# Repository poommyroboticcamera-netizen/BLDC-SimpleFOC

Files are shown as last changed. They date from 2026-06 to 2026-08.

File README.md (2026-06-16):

<div align="center">

# BLDC SimpleFOC

Custom STM32F405RG firmware and hardware reference files for a 3-phase BLDC inverter.







</div>

---

## Overview

`BLDC-SimpleFOC` is a hardware bring-up project for a custom 3-phase BLDC motor driver based on an STM32F405RG. The current firmware drives TIM1 complementary PWM outputs directly, adds dead-time at the timer level, reads phase voltage feedback with ADC pins, and exposes simple serial commands for early bench testing.

This repository is intended for controlled inverter testing, not finished production motor control. Start with a current-limited bench supply, low duty cycle, and oscilloscope verification before connecting a real motor load.

## What Is Included

| Area | Details |
| --- | --- |
| Firmware target | STM32F405RG using PlatformIO and Arduino |
| Runtime model | STM32duino FreeRTOS tasks |
| PWM output | TIM1 center-aligned 6-PWM complementary outputs |
| Switching frequency | `20 kHz` |
<<<<<<< HEAD
| Dead-time | `1.5us` configured in TIM1 BDTR |
=======
| Dead-time | `1.5 us` configured in TIM1 BDTR |
>>>>>>> 4c121442047dd9c6b4e7016d9e61324d03763788
| Control mode | Open-loop sinusoidal V/f style test waveform |
| Monitoring | Serial output plus phase voltage ADC reads |
| Hardware files | Schematic PDF, 3D STEP model, and firmware flow diagram |

## Repository Layout

```text
BLDC-SimpleFOC/
|-- firmware/
|   |-- include/        Project headers, when shared declarations are added
|   |-- lib/            Private PlatformIO libraries, when the firmware grows
|   |-- src/
|   |   `-- main.cpp    Main STM32 PWM, FreeRTOS, ADC, and serial logic
|   |-- test/           PlatformIO unit/integration test area
|   `-- platformio.ini  Board, framework, upload, monitor, and library config
|-- hardware/
|   |-- 3D_PCB_2026-06-15.step
|   |-- SCH_BLDC Drive_2026-06-15.pdf
|   |-- Custom FOC Firmware.drawio
|   |-- Custom FOC Firmware.drawio.png
|   |-- Custom FOC Firmware.drawio.svg
|   `-- README.md
|-- .gitattributes
|-- .gitignore
`-- README.md
```

## Hardware Pin Map

### PWM Outputs

TIM1 is configured for complementary high-side and low-side PWM outputs.

| Motor phase | High-side PWM | Low-side PWM | Timer channel |
| --- | --- | --- | --- |
| U | `PA8` | `PB13` | `TIM1_CH1 / TIM1_CH1N` |
| V | `PA9` | `PB14` | `TIM1_CH2 / TIM1_CH2N` |
| W | `PA10` | `PB15` | `TIM1_CH3 / TIM1_CH3N` |

### Phase Voltage Feedback

| Signal | MCU pin | Notes |
| --- | --- | --- |
| Phase A voltage | `PA0` | 12-bit ADC read |
| Phase B voltage | `PA1` | 12-bit ADC read |
| Phase C voltage | `PA2` | 12-bit ADC read |

The firmware currently assumes a phase voltage divider of:

```cpp
R1_PHASE = 56000.0f
R2_PHASE = 2200.0f
```

Adjust these constants in `firmware/src/main.cpp` if the resistor values on the board change.

## Firmware Behavior

The firmware creates two FreeRTOS tasks:

| Task | Period | Purpose |
| --- | ---: | --- |
| `TaskMotorControl` | `1 ms` | Updates the sinusoidal 3-phase PWM duty registers |
| `TaskMonitor` | `200 ms` | Reads serial commands, samples phase voltage ADCs, and prints telemetry |

Default runtime values:

| Setting | Default |
| --- | ---: |
| PWM frequency | `20 kHz` |
| Dead-time | `1.5us` |
| Initial duty | `5%` |
| Initial rotation speed | `1.0 deg/loop` |
| Serial baud | `115200` |

## Quick Start

Install VS Code with the PlatformIO extension, then clone and open the firmware project.

```bash
git clone https://github.com/poommyroboticcamera-netizen/BLDC-SimpleFOC.git
cd BLDC-SimpleFOC/firmware
```

Build the firmware:

```bash
pio run
```

Upload with ST-Link:

```bash
pio run --target upload
```

Open the serial monitor:

```bash
pio device monitor -b 115200
```

## Serial Commands

Commands are read from the serial monitor as one letter plus a numeric value.

| Command | Range | Example | Meaning |
| --- | --- | --- | --- |
| `D<value>` | `0` to `100` | `D5` | Set PWM duty percentage |
| `S<value>` | `0` to `20` | `S2.5` | Set electrical rotation speed in degrees per loop |

Recommended first commands:

```text
D0
S1
D2
D5
```

Increase duty slowly while watching the bench supply current and oscilloscope waveforms.

## Bring-Up Checklist

1. Confirm the schematic matches the PWM and ADC pin map above.
2. Power only the logic side and verify the serial boot message.
3. Scope `PA8`, `PA9`, `PA10`, `PB13`, `PB14`, and `PB15` before enabling motor power.
4. Confirm complementary PWM timing and dead-time.
5. Enable the gate driver with a current-limited supply.
6. Start with `D0`, then raise duty in small steps.
7. Verify phase order before connecting a mechanical load.
8. Add current sensing, fault handling, and closed-loop feedback before high-power testing.

## Hardware Documents

The hardware folder contains the current reference files:

| File | Purpose |
| --- | --- |
| [`SCH_BLDC Drive_2026-06-15.pdf`](hardware/SCH_BLDC%20Drive_2026-06-15.pdf) | Schematic export |
| [`3D_PCB_2026-06-15.step`](hardware/3D_PCB_2026-06-15.step) | 3D PCB model for mechanical review |
| [`Custom FOC Firmware.drawio.png`](hardware/Custom%20FOC%20Firmware.drawio.png) | Firmware flow diagram preview |
| [`Custom FOC Firmware.drawio`](hardware/Custom%20FOC%20Firmware.drawio) | Editable draw.io diagram |

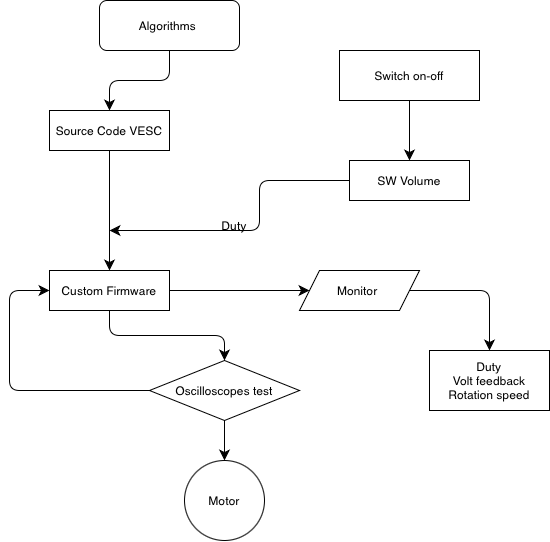
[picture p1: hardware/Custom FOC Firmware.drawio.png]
Firmware flow diagram


## Roadmap

- [ ] Clean up firmware comments and source encoding
- [ ] Add gate-driver enable and fault input handling
- [ ] Add current sensing and over-current protection
- [ ] Add magnetic encoder or Hall sensor feedback
- [ ] Add closed-loop FOC control after hardware validation
- [ ] Add known-good motor settings and oscilloscope captures
- [ ] Add PlatformIO CI build check

## Safety Notes

- Treat the inverter as high-energy hardware even at low voltage.
- Use a current-limited bench supply during first tests.
- Keep duty cycle low until all six PWM channels are verified.
- Do not run high power without fault handling and current protection.
- Disconnect motor power before changing wiring or probing low-side gate signals.

## Links

- Repository: [poommyroboticcamera-netizen/BLDC-SimpleFOC](https://github.com/poommyroboticcamera-netizen/BLDC-SimpleFOC)
- PlatformIO documentation: [docs.platformio.org](https://docs.platformio.org/)
- STM32duino documentation: [github.com/stm32duino](https://github.com/stm32duino)

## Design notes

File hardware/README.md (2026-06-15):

# Hardware

Hardware reference files for the custom STM32F405RG 3-phase BLDC driver.

## Files

| File | Description |
| --- | --- |
| [`SCH_BLDC Drive_2026-06-15.pdf`](SCH_BLDC%20Drive_2026-06-15.pdf) | Schematic export for electrical review |
| [`3D_PCB_2026-06-15.step`](3D_PCB_2026-06-15.step) | STEP model for mechanical fit checks and enclosure planning |
| [`Custom FOC Firmware.drawio`](Custom%20FOC%20Firmware.drawio) | Editable draw.io firmware/control-flow diagram |
| [`Custom FOC Firmware.drawio.png`](Custom%20FOC%20Firmware.drawio.png) | PNG preview of the firmware/control-flow diagram |
| [`Custom FOC Firmware.drawio.svg`](Custom%20FOC%20Firmware.drawio.svg) | SVG version of the diagram for scalable viewing |

## Firmware Flow Preview

Firmware flow diagram

## Board Interface Summary

| Function | Pins |
| --- | --- |
| High-side PWM | `PA8`, `PA9`, `PA10` |
| Low-side PWM | `PB13`, `PB14`, `PB15` |
| Phase voltage ADC | `PA0`, `PA1`, `PA2` |

## Review Checklist

- Confirm PWM pins match the gate-driver inputs in the schematic.
- Confirm the ADC phase-voltage divider values match the firmware constants.
- Verify gate-driver enable, fault, and protection pins before high-power tests.
- Check copper clearance, creepage, and thermal paths for the target bus voltage.
- Use the STEP file to check connector access, heatsink clearance, and mounting holes.

## Suggested Future Structure

As the hardware package grows, split files into focused folders:

```text
hardware/
|-- schematics/
|-- pcb/
|-- mechanical/
|-- simulation/
|-- bom/
`-- datasheets/
```

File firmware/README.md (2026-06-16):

# Firmware

PlatformIO firmware for the custom STM32F405RG 3-phase BLDC inverter.

## Stack

| Item | Value |
| --- | --- |
| Board | `genericSTM32F405RG` |
| Platform | `ststm32` |
| Framework | Arduino |
| RTOS | STM32duino FreeRTOS |
| Upload protocol | ST-Link |
| Serial monitor | `115200` baud |

## Source Layout

```text
firmware/
|-- include/        Shared headers, when needed
|-- lib/            Private PlatformIO libraries, when needed
|-- src/
|   `-- main.cpp    Main PWM, ADC, serial, and FreeRTOS logic
|-- test/           PlatformIO tests
|-- platformio.ini
`-- README.md
```

## Current Control Logic

The current firmware is an open-loop hardware bring-up program:

- Configures TIM1 for center-aligned complementary 6-PWM output.
- Applies `1.5us` dead-time in the advanced timer.
- Generates a 3-phase sinusoidal duty pattern.
- Reads phase voltage feedback on `PA0`, `PA1`, and `PA2`.
- Uses FreeRTOS to separate motor PWM updates from serial monitoring.

## Build

```bash
pio run
```

## Upload

```bash
pio run --target upload
```

## Monitor

```bash
pio device monitor -b 115200
```

## Serial Commands

| Command | Example | Description |
| --- | --- | --- |
| `D<value>` | `D5` | Set duty cycle in percent, from `0` to `100` |
| `S<value>` | `S2.5` | Set electrical speed in degrees per control loop, from `0` to `20` |

For first power-up, begin with:

```text
D0
S1
D2
```

## Hardware Pins

| Function | Pins |
| --- | --- |
| High-side PWM | `PA8`, `PA9`, `PA10` |
| Low-side PWM | `PB13`, `PB14`, `PB15` |
| Phase voltage ADC | `PA0`, `PA1`, `PA2` |

## Bring-Up Notes

- Verify all six PWM outputs with an oscilloscope before enabling motor power.
- Keep the duty cycle low during first tests.
- Use a current-limited bench supply.
- Add current sensing and fault handling before high-power operation.

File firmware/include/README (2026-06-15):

# Firmware Include Directory

Place shared project header files here when the firmware is split into multiple modules.

## When To Use This Folder

Use `include/` for declarations that need to be shared across files in `src/` or private libraries in `lib/`.

Good candidates:

- Pin maps
- Hardware configuration constants
- Shared structs and enums
- Public function declarations for firmware modules

## Example

```cpp
// include/board_config.h
#pragma once

#define PWM_U_HIGH PA8
#define PWM_V_HIGH PA9
#define PWM_W_HIGH PA10
```

Then include it from source files:

```cpp
#include "board_config.h"
```

## Current Status

The current firmware is still compact enough to keep the main hardware configuration in `src/main.cpp`. Move constants here when the code is refactored into dedicated PWM, ADC, serial, and protection modules.

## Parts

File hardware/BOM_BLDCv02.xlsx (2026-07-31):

No. | Quantity | Comment | Designator | Footprint | Value | Manufacturer Part
1 | 3 | 2.2uF | C18,C19,C20 | C0805 | 2.2uF | CL21A225KBQNNNE
2 | 6 | 22nF | C25,C26,C27,C28,C29,C30 | C1206 | 22nF | HHV1206R7223K631NSPJ
3 | 6 | 10uF | C31,C32,C33,C34,C35,C36 | C0805 | 10uF | GRM21BR61H106KE43L
4 | 12 | 100nF | C37,C38,C39,C40,C41,C42,C43,C44,C45,C58,C82,C83 | C0805 | 100nF | C0805X104K5RAC3123
5 | 4 | 1uF | C46,C47,C48,C50 | C0805 | 1uF | FS21X105K160ECG
6 | 1 | 2.2uF | C49 | C0805 | 2.2uF | FS21X105K160ECG
7 | 2 | 100nF | C59,C61 | C1206 | 100nF | CL31B104KBCNNNC
8 | 3 | 2.2uF | C60,C62,C76 | C1206 | 2.2uF | CL31B225KBHNNNE
9 | 2 | 4.7uF | C64,C66 | C0805 | 4.7uF | CL21A475KAQNNNE
10 | 2 | 22nF | C65,C68 | C0805 | 22nF | CL21B223KBANNNC
11 | 1 | 1uF | C72 | C0805 | 1uF | CL21B105KBFNNNE
12 | 3 | 22uF | C73,C74,C75 | C0805 | 22uF | CL21A226MAQNNNE
13 | 2 | 18pF | C77,C78 | C0603 | 18pF | C1608NP0180JGTS
14 | 2 | 2.2uF | C79,C80 | C0805 | 2.2uF | CL21B225KOFNNNE
15 | 1 | 10nF | C81 | C0805 | 10nF | C2012X7R2E103K125AA
16 | 3 | FR107 | D4,D5,D6 | SMA_L4.2-W2.7-LS5.3-FD |  | FR107
17 | 1 | SS510B | D7 | SMB_L4.3-W3.6-LS5.3-RD |  | SS510B
18 | 1 | SMF12A | D8 | SOD-123_L2.8-W1.8-LS3.7-RD |  | SMF12A
19 | 1 | SMF5.0A | D10 | SOD-123_L2.8-W1.8-LS3.7-RD |  | SMF5.0A
20 | 1 | SMF3.3A | D11 | SOD-123_L2.8-W1.8-LS3.7-RD |  | SMF3.3A
21 | 1 | XY-PZ2.54V-01-10P | H2 | HDR-TH_10P-P2.54-V-M_4 |  | XY-PZ2.54V-01-10P
22 | 2 | 2.54-1*3P | H3,H4 | HDR-TH_3P-P2.54-V-M-1 |  | 2.54-1*3P
23 | 1 | 68uH | L2 | IND-SMD_L7.8-W7.0_SCD0705N | 68uH | SM7850-680M(f)
24 | 1 | KT-0805Y | LED1 | LED0805-R-RD |  | KT-0805Y
25 | 6 | IRFS7530TRL7PP | Q1,Q2,Q3,Q4,Q5,Q6 | D2PAK-7_L10.6-W9.6-P1.27-LS15.9-BR |  | IRFS7530TRL7PP
26 | 3 | EG3112D | R20,R39,R40 | SOP-8_L5.0-W3.9-P1.27-LS6.0-BL-1 |  | EG3112D
27 | 3 | 56K | R32,R59,R60 | R0805_NEW | 56K | RK73H1JTTD10R0F
28 | 6 | 10Ω | R41,R42,R43,R44,R45,R46 | R0603 | 10Ω | WF06P10R0FTL
29 | 3 | 1mΩ | R47,R50,R53 | R2512 | 1mΩ | HIXD25LR001F
30 | 6 | 1kΩ | R48,R49,R51,R52,R54,R55 | R0805 | 1kΩ | AS05W3J0102T5E
31 | 3 | 2.2kΩ | R56,R57,R58 | R0805 | 2.2kΩ | RK73B2ATTD222J
32 | 5 | 10kΩ | R61,R85,R86,R88,R89 | R0805 | 10kΩ | AS05W3J0102T5E
33 | 1 | 30kΩ | R63 | R0603 | 30kΩ | RMC060330K5%N
34 | 1 | 274kΩ | R64 | R0805 | 274kΩ | WR08X2743FTL
35 | 4 | 10kΩ | R65,R66,R69,R70 | R0603 | 10kΩ | KTR03EZPJ103
36 | 1 | 45.3kΩ | R71 | R0603 | 45.3kΩ | WR06X4532FTL
37 | 1 | 5.1kΩ | R72 | R1206 | 5.1kΩ | RK73B2BTTD512J
38 | 9 | 0Ω | R73,R74,R75,R76,R77,R78,R79,R80,R81 | R1206 | 0Ω | 1206W4F0000T5E
39 | 1 | 4.3kΩ | R82 | R0603 | 4.3kΩ | RTT034301FTP
40 | 1 | 73.2kΩ | R83 | R0603 | 73.2kΩ | TD03G7322BT
41 | 1 | 120Ω | R84 | R0805 | 120Ω | CRGCQ0805F120R
42 | 2 | 1kΩ | R87,R90 | R0805 | 1kΩ | TP0805B1K00P0510Z
43 | 4 | TS-1088-AR02016 | SW1,SW2,SW3,SW4 | SW-SMD_L3.9-W3.0-P4.45 |  | TS-1088-AR02016
44 | 2 | 1935174 | U12,U20 | CONN-TH_3P-P5.00_1935174 |  | 1935174
45 | 3 | INA181A1IDBVR | U13,U14,U15 | SOT-23-6_L2.9-W1.6-P0.95-LS2.8-TL |  | INA181A1IDBVR
46 | 1 | STM32F405RGT6 | U18 | LQFP-64_L10.0-W10.0-P0.50-LS12.0-BL |  | STM32F405RGT6
47 | 3 | xh2.54-4p | U19,U27,U28 | CONN-TH_4P-P2.50-XH2.54-4P |  | xh2.54-4p
48 | 1 | SCT2A23STER | U21 | ESOP-8_L4.9-W3.9-P1.27-LS6.0-BL-EP-1 |  | SCT2A23STER
49 | 1 | 68pF | U22 | C0805 | 68pF | HGC0805G0680J500NTGJ
50 | 2 | RY8120 | U23,U25 | SOT-23-6_L2.9-W1.6-P0.95-LS2.8-BL |  | RY8120
51 | 2 | 2.2uH | U24,U26 | IND-SMD_L2.5-W2.0-VLS252012CX-150M |  | 2.2uH
52 | 1 | MCP2551-I/SN | U29 | SOIC-8_L4.9-W3.9-P1.27-LS6.0-BL |  | MCP2551-I/SN
53 | 1 | 8MHz | X4 | CRYSTAL-SMD_4P-L3.2-W2.5-BL | 8MHz | X32258MOB4SI

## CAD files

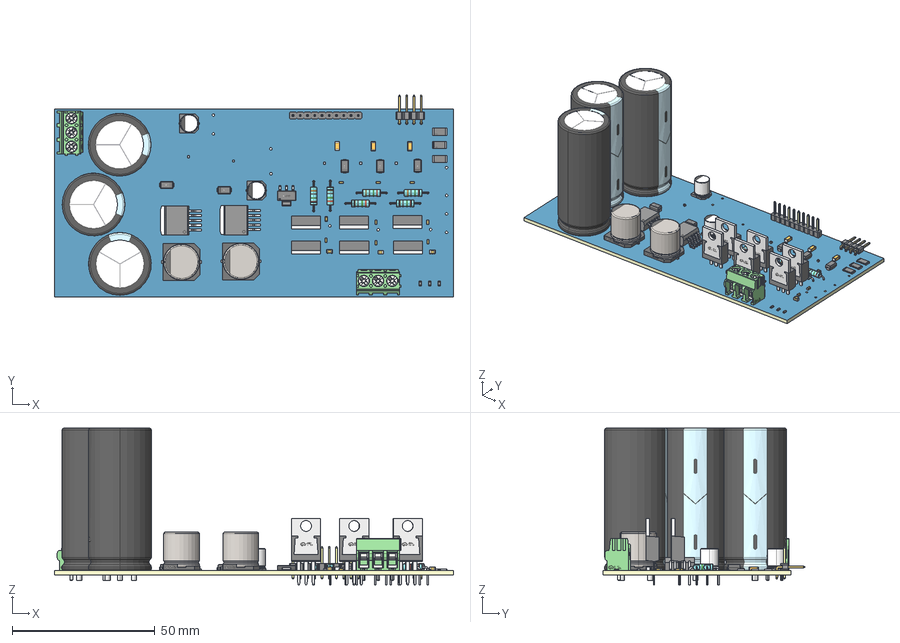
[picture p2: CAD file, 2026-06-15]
hardware/3D_PCB_2026-06-15.step
140.0 x 70.9 x 55.0 mm
Board~qXUS
TopCopper~qXUS
BottomCopper~qXUS
TopFpcStiffener~qXUS
BottomFpcStiffener~qXUS
L2~IND-SMD_L12.0-W12.0~SMD-PIND_L12.5-W12.5-H8.0~qXUS x 2
R9~SOP-8_L5.0-W3.9-P1.27-LS6.0-BL-1~SOP-8_ L5.0-W3.9-P1.27-LS6.0-BL-1~qXUS x 3
C1206~C1206_L3.2-W1.6-H1.3~qXUS x 3
C0805~C0805_L2.0-W1.3-H1.3~qXUS x 3
C0603~C0603_L1.6-W0.8-H0.8~qXUS x 9
R0603~R0603~qXUS x 3
TO-263-5_L10.1-W8.7-P1.70-LS14.4-BR~TO-263-5_ L10.13-W8.74-P1.70-LS14.38-BR~qXUS x 2
TO-220-3_L10.0-W4.5-P2.54-L~TO-220-3_L10.0-W4.5-P2.54-L~qXUS x 6
CAP-SMD_BD6.3-L6.6-W6.6-LS7.2-FD~CAP-SMD_BD6.3-L6.6-W6.6-LS7.2-FD~qXUS x 2
CAP-TH_BD22.0-P10.00-D2.3-FD~CAP-TH_BD22.0-H50.0-P10.0~qXUS x 3
CAP-SMD_BD12.5-L13.0-W13.0-LS14.0-FD~CAP-SMD_ BD12.5-L13.0-W13.0-LS14.0-FD~qXUS x 2
HDR-TH_10P-P2.54-V-M_4~HDR-TH_10P-P2.54-V-M_4~qXUS
SMA_L4.2-W2.7-LS5.3-FD~SMA_L4.2-W2.7-LS5.3-RD~qXUS x 3
HDR-TH_4P-P2.54-H-M-W10.2~HDR-TH_4P-P2.54-H-M-W10.2~qXUS
CONN-TH_3P-P5.00_1935174~CONN-TH_3P-P5.00_1935174~qXUS x 2
RES-TH_BD2.4-L6.3-P10.30-D0.6~RES-TH_BD2.4-L6.3-P10.30-D0.6~qXUS x 6
R2010~R2010_L5.0-W2.5-H0.6~qXUS x 3
SOT-223-3_L6.5-W3.4-P2.30-LS7.0-BR~SOT-223-4P_ L6.5-W3.5-H1.6-LS7.0-P2.30~qXUS
SMA_L4.4-W2.8-LS5.4-RD~SMA_L4.4-W2.8-LS5.4-RD~qXUS x 2

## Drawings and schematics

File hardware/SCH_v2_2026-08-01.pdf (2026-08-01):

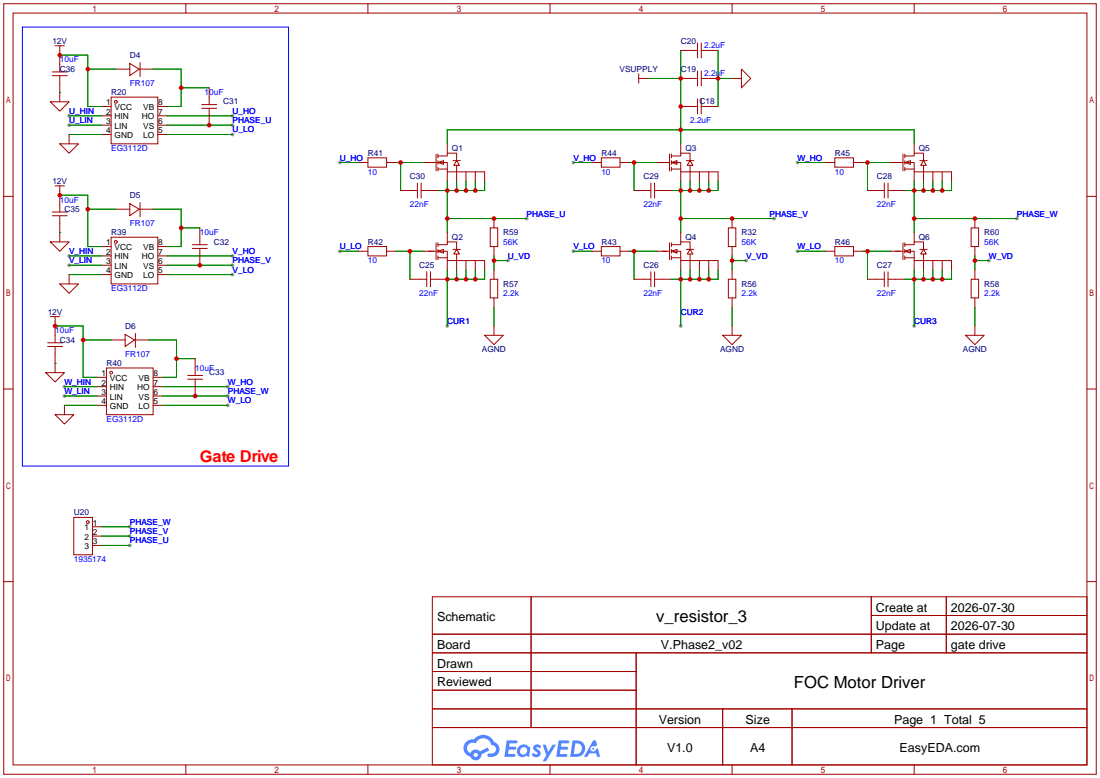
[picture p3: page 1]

Schematic | v_resistor_3 | Create at | 2026-07-30

Update at | 2026-07-30

Board | V.Phase2_v02 | Page | gate drive
Drawn | | FOC Motor Driver
Reviewed

Version | Size | Page 1 Total 5
V1.0 | A4 | EasyEDA.com

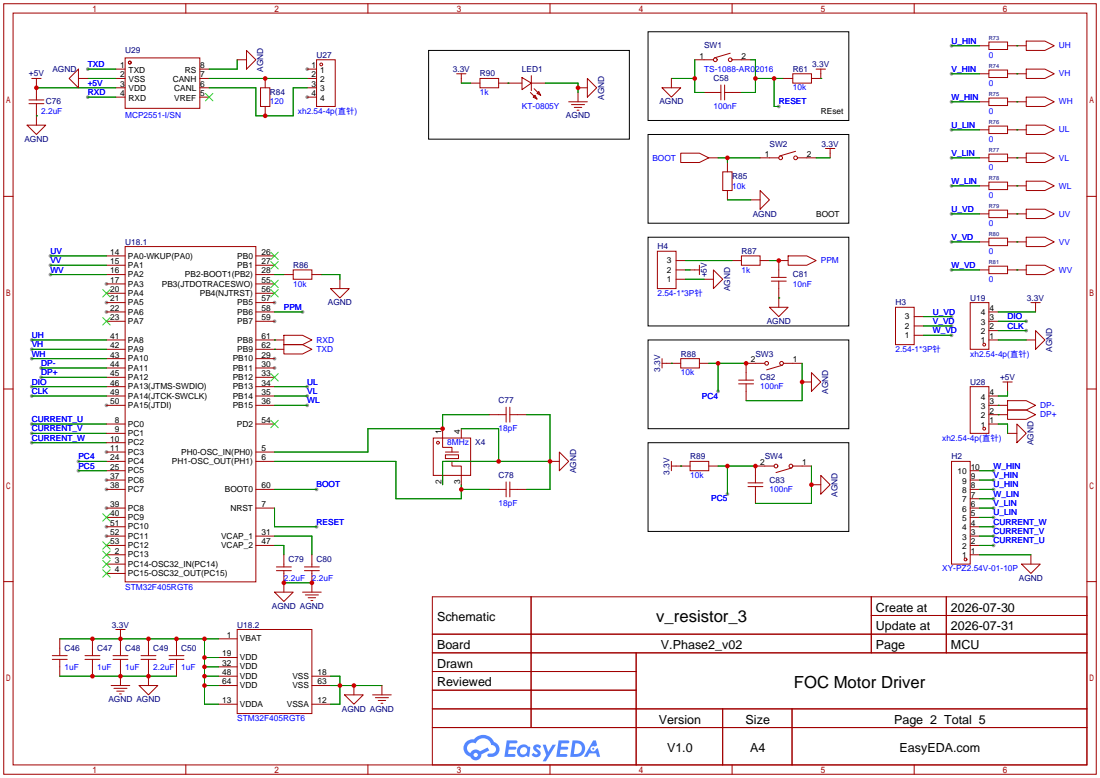
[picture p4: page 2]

Schematic | v_resistor_3 | Create at | 2026-07-30

Update at | 2026-07-31

Board | V.Phase2_v02 | Page | MCU
Drawn | | FOC Motor Driver
Reviewed

VDD 19

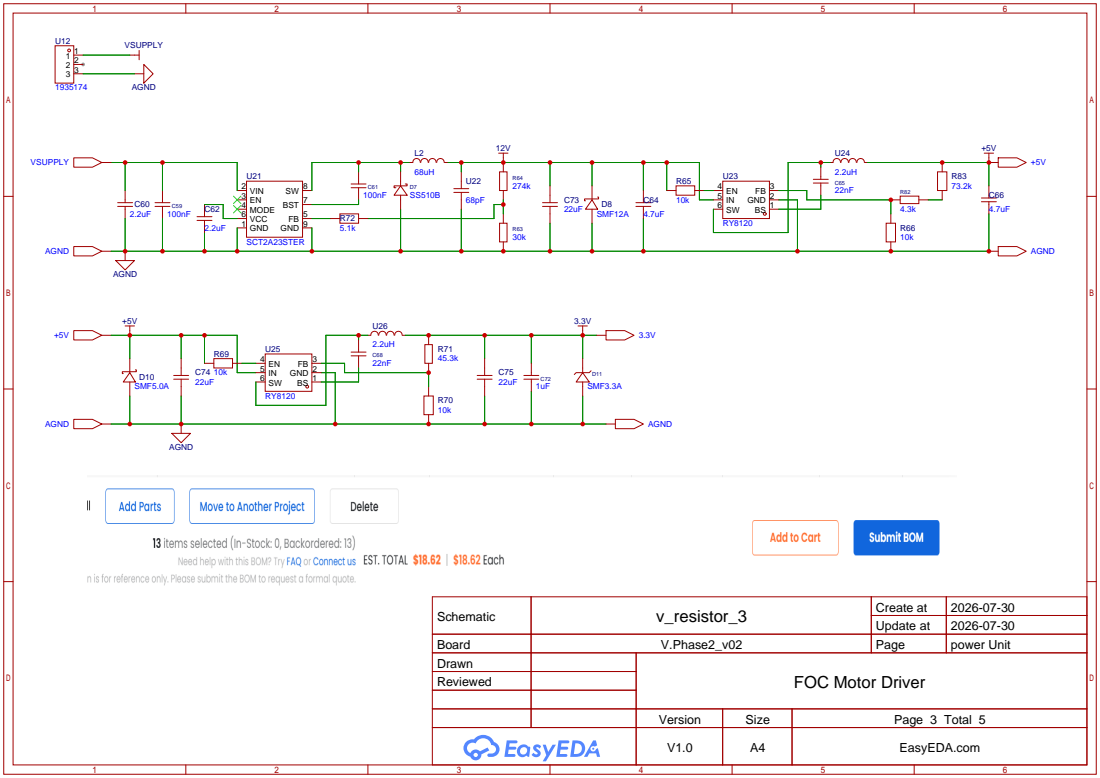
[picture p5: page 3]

Schematic | v_resistor_3 | Create at | 2026-07-30

Update at | 2026-07-30

Board | V.Phase2_v02 | Page | power Unit
Drawn | | FOC Motor Driver
Reviewed

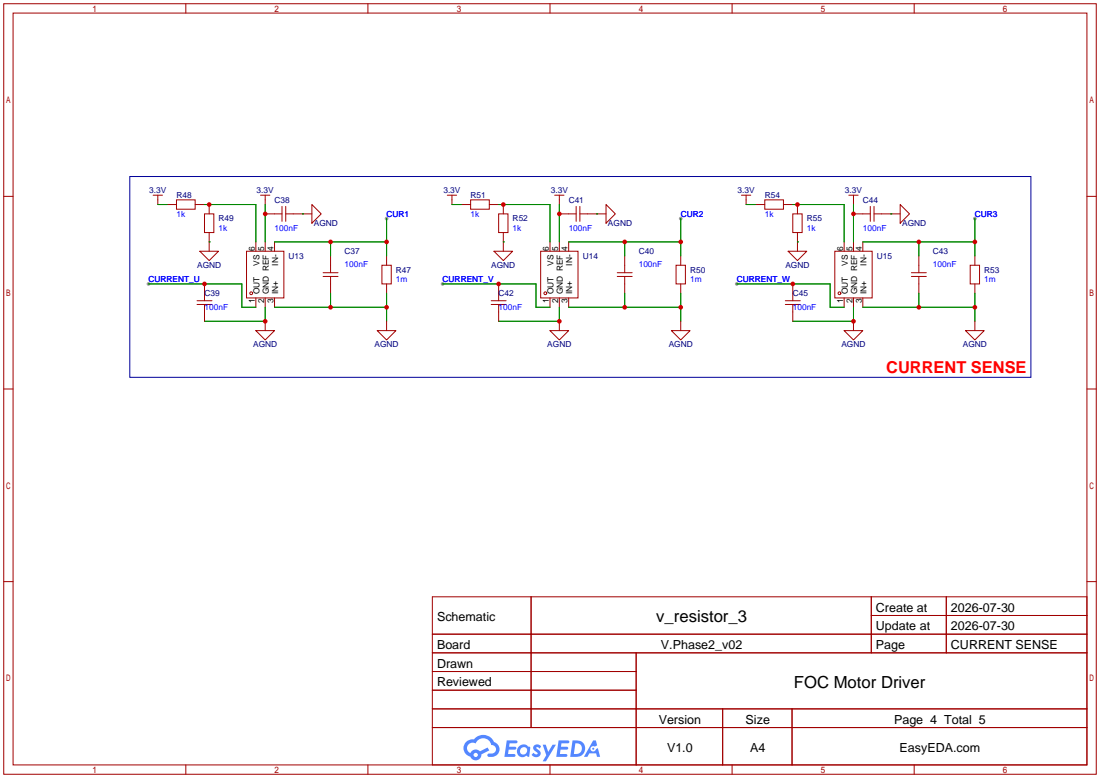
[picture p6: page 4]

Schematic | v_resistor_3 | Create at | 2026-07-30

Update at | 2026-07-30

Board | V.Phase2_v02 | Page | CURRENT SENSE
Drawn | | FOC Motor Driver
Reviewed

# RLC

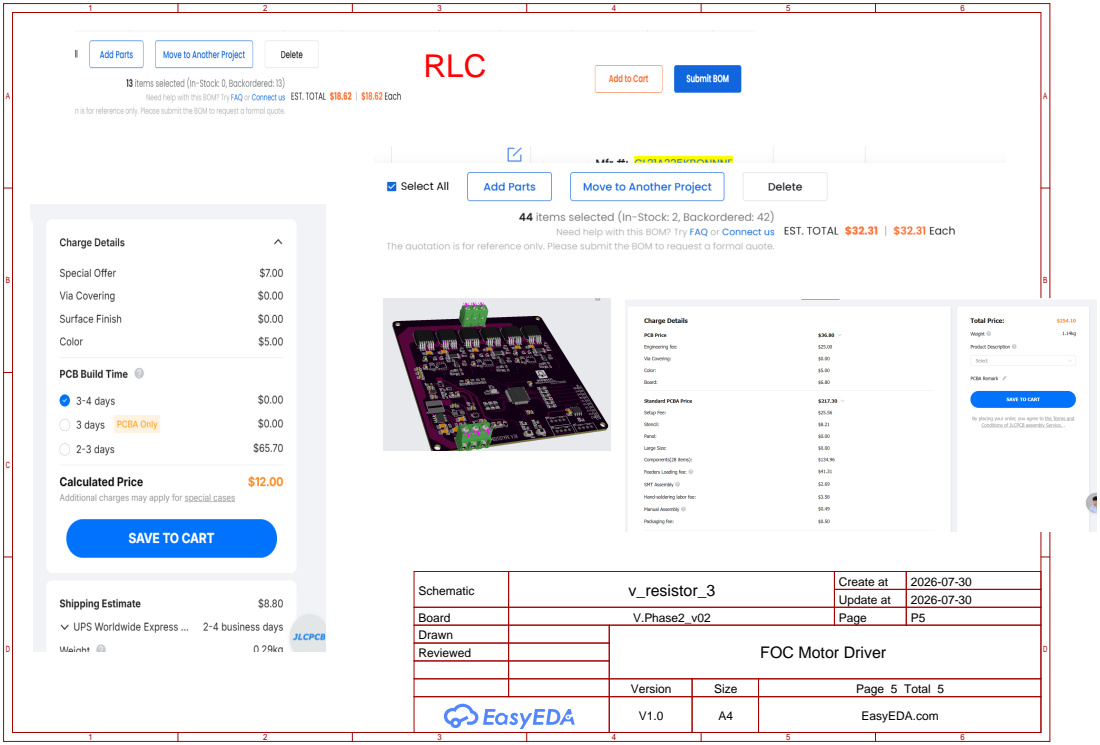
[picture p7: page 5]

Schematic | v_resistor_3 | Create at | 2026-07-30

Update at | 2026-07-30

Board | V.Phase2_v02 | Page | P5
Drawn | | FOC Motor Driver
Reviewed

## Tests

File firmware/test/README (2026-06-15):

# Firmware Tests

This folder is reserved for PlatformIO tests.

## Useful Test Targets

As the firmware becomes more modular, add tests for:

- Serial command parsing
- Duty-cycle clamping
- Speed command limits
- ADC voltage-divider conversion
- PWM phase math
- Gate-driver fault-state behavior

## Running Tests

From the `firmware/` directory:

```bash
pio test
```

For early hardware bring-up, most validation is still manual with a serial monitor, oscilloscope, and current-limited bench supply. Automated tests should be added when logic is moved out of `src/main.cpp` into smaller modules.

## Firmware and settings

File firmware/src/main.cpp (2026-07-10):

#include <Arduino.h>
#include <math.h>

/* ================= CONFIG ================= */
static const float BUS_VOLTAGE = 24.0f;
static const uint32_t PWM_FREQ_HZ = 20000;
static const uint32_t TIMER_CLOCK_HZ = 168000000;

static const uint8_t pole_pairs = 6;

/* motor control */
static float targetMechanicalRpm = -300.0f;
static float currentMechanicalRpm = 0.0f;
static float rampRpmPerSecond = 80.0f;

static float electricalAngle = 0.0f;
static float electricalRps = 0.0f;

/* control */
static float targetUqVolts = 2.5f;
static float startBoost = 2.8f;

/* TIM */
static uint16_t tim1Arr = 0;

/* ================= UTILS ================= */
static float clampf(float x, float a, float b)
{
    if (x < a) return a;
    if (x > b) return b;
    return x;
}

/* ================= DEADTIME ================= */
static uint8_t deadtimeTicksFromUs(float us)
{
    uint32_t ticks = (uint32_t)(us * TIMER_CLOCK_HZ / 1e6f);

    if (ticks <= 127) return (uint8_t)ticks;

    ticks >>= 1;
    if (ticks > 63) ticks = 63;

    return (uint8_t)(0x80 | ticks);
}

/* ================= GPIO + TIM1 ================= */
static void setupPWM()
{
    RCC->AHB1ENR |= RCC_AHB1ENR_GPIOAEN | RCC_AHB1ENR_GPIOBEN;
    RCC->APB2ENR |= RCC_APB2ENR_TIM1EN;

    /* PA8 PA9 PA10 = TIM1_CH1 CH2 CH3 */
    GPIOA->MODER &= ~((3 << (8 * 2)) | (3 << (9 * 2)) | (3 << (10 * 2)));
    GPIOA->MODER |=  ((2 << (8 * 2)) | (2 << (9 * 2)) | (2 << (10 * 2)));

    /* PB13 PB14 PB15 = TIM1_CH1N CH2N CH3N */
    GPIOB->MODER &= ~((3 << (13 * 2)) | (3 << (14 * 2)) | (3 << (15 * 2)));
    GPIOB->MODER |=  ((2 << (13 * 2)) | (2 << (14 * 2)) | (2 << (15 * 2)));

    /* AF1 = TIM1 */
    GPIOA->AFR[1] &= ~((0xF << 0) | (0xF << 4) | (0xF << 8));
    GPIOA->AFR[1] |=  ((1 << 0) | (1 << 4) | (1 << 8));

    GPIOB->AFR[1] &= ~((0xF << 20) | (0xF << 24) | (0xF << 28));
    GPIOB->AFR[1] |=  ((1 << 20) | (1 << 24) | (1 << 28));

    /* TIM1 base */
    TIM1->CR1 = 0;
    TIM1->PSC = 0;

    tim1Arr = (uint16_t)((TIMER_CLOCK_HZ / (2 * PWM_FREQ_HZ)) - 1);
    TIM1->ARR = tim1Arr;

    /* PWM mode 1 on CH1 CH2 CH3 */
    TIM1->CCMR1 =
        TIM_CCMR1_OC1M_1 | TIM_CCMR1_OC1M_2 |
        TIM_CCMR1_OC2M_1 | TIM_CCMR1_OC2M_2;

    TIM1->CCMR2 =
        TIM_CCMR2_OC3M_1 | TIM_CCMR2_OC3M_2;

    /* Enable high-side and low-side outputs */
    TIM1->CCER =
        TIM_CCER_CC1E | TIM_CCER_CC1NE |
        TIM_CCER_CC2E | TIM_CCER_CC2NE |
        TIM_CCER_CC3E | TIM_CCER_CC3NE;

    /* Deadtime + main output enable */
    uint8_t dt = deadtimeTicksFromUs(1.0f);

    TIM1->BDTR =
        TIM_BDTR_MOE |
        TIM_BDTR_OSSR |
        TIM_BDTR_OSSI |
        dt;

    /* Center-aligned mode + preload */
    TIM1->CR1 = TIM_CR1_CMS_0 | TIM_CR1_ARPE;

    TIM1->EGR = TIM_EGR_UG;

    TIM1->CCR1 = tim1Arr / 2;
    TIM1->CCR2 = tim1Arr / 2;
    TIM1->CCR3 = tim1Arr / 2;

    TIM1->CR1 |= TIM_CR1_CEN;
}

/* ================= PWM WRITE ================= */
static void writeDuty(float da, float db, float dc)
{
    da = clampf(da, 0.02f, 0.98f);
    db = clampf(db, 0.02f, 0.98f);
    dc = clampf(dc, 0.02f, 0.98f);

    uint16_t top = tim1Arr + 1;

    TIM1->CCR1 = (uint16_t)(da * top);
    TIM1->CCR2 = (uint16_t)(db * top);
    TIM1->CCR3 = (uint16_t)(dc * top);
}

/* ================= SVPWM ================= */
static void setSVPWM(float alpha, float beta)
{
    float v1 = beta;
    float v2 = -0.5f * beta + 0.8660254f * alpha;
    float v3 = -0.5f * beta - 0.8660254f * alpha;

    float vmax = fmaxf(v1, fmaxf(v2, v3));
    float vmin = fminf(v1, fminf(v2, v3));

    float offset = 0.5f * (vmax + vmin);

    v1 -= offset;
    v2 -= offset;
    v3 -= offset;

    float da = 0.5f + (v1 / BUS_VOLTAGE);
    float db = 0.5f + (v2 / BUS_VOLTAGE);
    float dc = 0.5f + (v3 / BUS_VOLTAGE);

    writeDuty(da, db, dc);
}

/* ================= OPEN LOOP FOC ================= */
static void openLoopFOC(float theta, float uq)
{
    float alpha = -uq * sinf(theta);
    float beta  =  uq * cosf(theta);

    setSVPWM(alpha, beta);
}

/* ================= RAMP ================= */
static void updateRamp(float dt)
{
    float step = rampRpmPerSecond * dt;

    if (currentMechanicalRpm < targetMechanicalRpm)
    {
        currentMechanicalRpm += step;
        if (currentMechanicalRpm > targetMechanicalRpm)
            currentMechanicalRpm = targetMechanicalRpm;
    }
    else
    {
        currentMechanicalRpm -= step;
        if (currentMechanicalRpm < targetMechanicalRpm)
            currentMechanicalRpm = targetMechanicalRpm;
    }

    electricalRps = currentMechanicalRpm * pole_pairs / 60.0f;
}

/* ================= ALIGN ROTOR ================= */
static void alignRotor()
{
    for (int i = 0; i < 600; i++)
    {
        openLoopFOC(0.0f, startBoost);
        delay(2);
    }
}

/* ================= SETUP ================= */
void setup()
{
    delay(1000);

    setupPWM();

    alignRotor();

    electricalAngle = 0.0f;
}

/* ================= LOOP ================= */
void loop()
{
    static uint32_t last = micros();

    uint32_t now = micros();
    float dt = (now - last) * 1e-6f;
    last = now;

    if (dt <= 0.0f || dt > 0.05f)
        dt = 0.001f;

    updateRamp(dt);

    electricalAngle += 6.2831853f * electricalRps * dt;

    while (electricalAngle > 6.2831853f)
        electricalAngle -= 6.2831853f;

    float uq = (currentMechanicalRpm < 5.0f) ? startBoost : targetUqVolts;

    openLoopFOC(electricalAngle, uq);
}

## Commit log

2026-06-09 Update main.cpp
    Upgrade to vesc source
2026-06-09 เพิ่มแล้ว Custom FOC Firmware.drawio
2026-06-09 เพิ่มแล้ว Custom FOC Firmware.drawio.png
2026-06-09 เพิ่มแล้ว Custom FOC Firmware.drawio.svg
2026-06-15 Add hardware PDF and STEP files
    [3D_PCB_2026-06-15.step]
2026-07-31 Add files via upload
    file PCB and Project EDA
    [BOM_BLDCv02.xlsx, PickAndPlace_BLDCV02.xlsx]
